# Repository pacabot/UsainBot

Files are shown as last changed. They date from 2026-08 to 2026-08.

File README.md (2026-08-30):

# UsainBot

Robot suiveur de ligne de l'équipe **Pacabot**, conçu pour l'épreuve **Formule 1** du
Tournoi National de Robotique Sumo (règlement v2.11, 2025).

Course de vitesse contre la montre sur circuit fermé : ligne noire de 19 mm sur bâche
blanche, rayon de virage minimum de 200 mm, lignes droites jusqu'à 6 m. Trois phases de
qualification, de difficulté croissante — Q3 piste nue, Q2 avec un cube de 100 mm à
éviter sans contact, Q1 avec en plus un virage à gauche escamoté et un mur de 100 mm de
haut placé à 150 mm à gauche de l'axe de la piste absente.

## Organisation

```
electronics/      projet KiCad — schéma, PCB, table de bibliothèques
  kicad-lib/      empreintes et modèles 3D propres au projet
firmware/         configuration STM32CubeMX, puis le code
mechanics/        sources FreeCAD du châssis, des supports et de la carte
documentation/    document d'architecture
rules/            règlement de l'épreuve
```

Les bibliothèques sont référencées en `${KIPRJMOD}/kicad-lib/…` : le dépôt se clone et
s'ouvre tel quel, sans chemin absolu ni variable d'environnement à déclarer.

## Architecture

Le document de conception complet — choix du microcontrôleur, schémas blocs, implantation,
élévations, affectation des broches, nomenclature JLCPCB et revue de conception en
trente-sept points — est ici :

**[`documentation/architecture-usainbot.html`](documentation/architecture-usainbot.html)**

| Fonction | Choix | JLCPCB |
|---|---|---|
| Microcontrôleur | STM32H723VGT6, Cortex-M7 550 MHz, LQFP100 | `C730142` |
| Capteur de ligne | 12 × ITR8307, pas 10 mm, émetteurs pulsés | `C81632` |
| Télémétrie | 3 × OPV302 + BPW77, détection synchrone | pose manuelle |
| Inertie | LSM6DSO, 6 axes, SPI | `C2655100` |
| Puissance moteurs | 2 × DRV8874, 6 A crête, retour de courant | `C1855818` |
| Charge | BQ25887, 2S élévateur depuis USB-C, équilibrage | `C2761614` |
| Alimentation | Pack 2S LiFePO4, bus 5,0–7,3 V, buck 3,3 V | `C3200405` |

## Géométrie

La garde au sol vaut `rayon de roue − hauteur de l'axe moteur au-dessus du dessous de
carte`. Avec les roues Pololu 40 × 7 retenues et le support N20 nu, l'axe est à 11 mm et
la garde serait de 9 mm — au-delà de la plage utile de l'ITR8307, qui travaille entre 2 et
4 mm. **Quatre millimètres d'entretoises sur mesure** sous le support portent l'axe à
15 mm et ramènent la garde à 5 mm.

Conséquence à répercuter : le décalage en Z des modèles 3D du moteur et du support, dans
`electronics/kicad-lib/Pacabot.pretty/`, devra suivre l'épaisseur d'entretoise retenue.

## Points ouverts

- **Départ par télémètre.** Le chapitre 2 du règlement énumère trois moyens de départ —
  interrupteur, bouton poussoir, jack — et cette liste se lit comme limitative. Question à
  poser aux organisateurs ; un bouton physique conforme est conservé en secours.
- **Porteuse de la télémétrie.** À choisir hors de la bande de scintillement des
  éclairages et à l'écart des 38 kHz des barrières de chronométrage, avec un codage propre
  au robot pour la réjection par corrélation. À caler sur plaque d'essai. Rester à 12 mA :
  monter en fréquence pour débloquer les 48 mA de l'OPV302 ne change pas la puissance
  moyenne, donc pas la portée — les deux régimes donnent 1,26 mW. Le seul levier de portée
  est la surface du récepteur.
- **Inclinaison des diodes.** 4° vers le haut, soudées à plat sur la carte. Le rayon bas du
  faisceau monte alors de 35 mm par mètre et n'atteint jamais la bâche, mais le centre passe
  au-dessus d'un cube de 100 mm au-delà d'environ un mètre.
- **Approvisionnement.** OPV302 et BPW77 ne sont probablement pas dans la bibliothèque
  JLCPCB : pose manuelle des six composants de la languette à prévoir.
- **Poussée de la turbine.** À mesurer sous 6,4 V et non sous les 8,4 V pour lesquels les
  ensembles ESC et brushless du commerce sont calibrés.

## Contenu tiers

- `rules/Reglement-Formule-1-v2.11.pdf` — règlement rédigé par Frédéric Giamarchi et
  Jean-Roch Vaillé pour le Tournoi National de Robotique Sumo. Publié sur
  [robot-sumo.fr](https://robot-sumo.fr), reproduit ici pour le confort de travail de
  l'équipe. Tous droits réservés à leurs auteurs.
- `mechanics/battery-holder-4xaa-1.snapshot.1/` — modèle de porte-piles téléchargé,
  conservé pour référence. Sans objet depuis le passage à un pack 2S LiFePO4.
- `electronics/kicad-lib/3d/GM12-N20_*.step` — dérivés du modèle Waveshare du
  motoréducteur. Voir `electronics/kicad-lib/README.md` pour la provenance et les réserves
  de cotation.

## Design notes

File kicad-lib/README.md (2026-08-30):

# Bibliothèque KiCad — Pacabot Junior

## Motor_GM12-N20_Bracket

Empreinte **mécanique** (aucune connexion électrique) du moteur GM12-N20 6 V 1:30
monté sur son support N20/N30.

- Origine = **milieu des deux trous de fixation**
- Axe moteur suivant **Y**, arbre de sortie vers **−Y**
- Face avant du support **6,00 mm en retrait** de la face de sortie d'axe
- 2 trous non métallisés **Ø 2,2 mm** (M2 avec jeu), **entraxe 18,00 mm**
- Emprise totale : X ±12,75 mm, Y −22,45 → +17,85 mm (40,30 mm de long)
- `F.Fab` : contour support + corps moteur + arbre — `F.SilkS` : support seul

Régénérer après une mesure : éditer les constantes en tête de
`gen_motor_footprint.py` puis `python3 gen_motor_footprint.py`.

## Modèles 3D (`3d/`)

Six fichiers STEP **colorés**, déjà positionnés sur l'origine de l'empreinte
(offset et rotation à 0 dans le `.kicad_mod`, rien à régler dans KiCad).

| Fichier | Couleur | Origine |
|---|---|---|
| `GM12-N20_bracket.step` | blanc ABS | `n20_motor_mounting_bracket001` de `../motorHolder.fcstd` |
| `GM12-N20_motor_gearbox.step` | laiton | STEP Waveshare, faces à Y ≥ 16,07 (réducteur + arbre) |
| `GM12-N20_motor_can.step` | nickel | STEP Waveshare, faces à 1,0 ≤ Y < 16,07 |
| `GM12-N20_motor_encoder.step` | sombre | STEP Waveshare, faces à Y < 1,0 |
| `Pololu_wheel_40x7_hub.step` | blanc | STEP officiel Pololu, faces à r ≤ 18,3 mm |
| `Pololu_wheel_40x7_tire.step` | noir | STEP officiel Pololu, faces à r > 18,3 mm |

La roue est le modèle officiel Pololu du 40×7 mm **blanc** — exactement la
référence 1454 achetée. Séparation moyeu/gomme au rayon 18,25 mm, d'après le
plan coté Pololu : moyeu Ø36,5 mm, hors-tout Ø40,0 mm.

Position de la roue : emmanchée à fond, face extérieure au bout d'arbre.

### Couleurs

KiCad 10 n'utilise plus que du STEP (aucun `.wrl` livré) : la couleur doit être
portée par le fichier lui-même. FreeCAD en mode console ne sait pas les écrire —
pas de `ViewObject`. Les entités `COLOUR_RGB` / `STYLED_ITEM` sont donc ajoutées
en post-traitement par `colorize_step.py`, sur le même motif que les modèles
livrés avec KiCad. Pour changer une teinte : éditer `PALETTE` en tête du script,
régénérer le STEP concerné, puis relancer `python3 colorize_step.py`.

## Provenance des cotes

| Cote | Valeur | Source |
|---|---|---|
| **Entraxe des trous** | **18,00 mm** | vue de dessus de la datasheet Handson `GA12-N20-Bracket.pdf` — **confirmé au pied à coulisse sur la pièce réelle** |
| Diamètre des trous | M2 (écrou hexagonal) | datasheet — porté à 2,20 mm sur la carte pour le jeu |
| Largeur hors-tout | 25,00 mm | datasheet |
| Profondeur | 11,50 mm | datasheet (dont 8,50 mm pour la zone des oreilles) |
| **Retrait support / face de sortie d'axe** | **6,00 mm** | **mesuré sur le montage réel** |
| Section moteur | 10 × 12 mm | plan coté Waveshare + STEP |
| Longueur totale moteur | 40,30 mm | STEP Waveshare |
| Arbre | Ø3 mm, méplat D 2,5 mm, 9,2 mm | STEP Waveshare |

## Réserves

1. **Le 3D du support ne correspond pas exactement à la pièce réelle.**
   `n20_motor_mounting_bracket001` (extrait de `../motorHolder.fcstd`) mesure
   27,50 mm de large pour un entraxe de 18,50 mm, alors que la pièce achetée
   fait 25,00 mm pour 18,00 mm d'entraxe. C'est un modèle téléchargé, pas un
   relevé de la pièce. **L'empreinte est juste** (cotes datasheet vérifiées au
   pied à coulisse) ; seul le rendu 3D est indicatif, avec 0,25 mm d'écart par
   trou et 1,25 mm par côté.

2. **Attention au texte de la datasheet Handson** : son résumé annonce
   « *Pitch: about 16 mm* », ce qui est faux. La cote de 18,0 mm portée sur la
   vue de dessus, dont les lignes d'attache aboutissent au centre des logements
   d'écrou, est la bonne.

3. **Le 3D du moteur est un Waveshare DCGM-N20-12V-EN-200RPM (12 V, 1:150)**,
   pas le GM12-N20 6 V 1:30 réellement acheté. Même famille et mêmes cotes
   d'enveloppe, mais le bloc encodeur en bout diffère : le modèle porte un
   connecteur ZH1.5-6PIN là où la pièce réelle a un faisceau.

4. Le bloc encodeur du modèle descend à Z = −0,41 mm (très légèrement sous le
   plan de la carte) et culmine à Z = 18,50 mm.

5. Le sens de montage du support est **confirmé** : la face à 7,25 mm de l'axe
   des trous est bien côté arbre. Le support serre le **corps du moteur**, pas le
   réducteur — il couvre 3,03 mm de réducteur et 8,47 mm de moteur.

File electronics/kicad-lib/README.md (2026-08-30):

# Bibliothèque KiCad — UsainBot

## Motor_GM12-N20_Bracket

Empreinte **mécanique** (aucune connexion électrique) du moteur GM12-N20 6 V 1:30
monté sur son support N20/N30.

- Origine = **milieu des deux trous de fixation**
- Axe moteur suivant **Y**, arbre de sortie vers **−Y**
- Face avant du support **6,00 mm en retrait** de la face de sortie d'axe
- 2 trous non métallisés **Ø 2,2 mm** (M2 avec jeu), **entraxe 18,00 mm**
- Emprise totale : X ±12,75 mm, Y −22,45 → +17,85 mm (40,30 mm de long)
- `F.Fab` : contour support + corps moteur + arbre — `F.SilkS` : support seul

Régénérer après une mesure : éditer les constantes en tête de
`gen_motor_footprint.py` puis `python3 gen_motor_footprint.py`.

## Symboles (`Pacabot.kicad_sym`)

Neuf symboles absents des bibliothèques KiCad, ou dont le typage de broches
rendait l'ERC inexploitable. Régénérer avec `../tools/gen_lib.py`.

| Symbole | Pourquoi il est là |
|---|---|
| `DRV8874PWPR` | KiCad ne fournit que les DRV8870/71/72. Brochage HTSSOP-16 saisi depuis la fiche TI SLVSF66A : `EN/IN1` 1, `PH/IN2` 2, `nSLEEP` 3, `nFAULT` 4, `VREF` 5, `IPROPI` 6, `IMODE` 7, `OUT1` 8, `PGND` 9, `OUT2` 10, `VM` 11, `VCP` 12, `CPH` 13, `CPL` 14, `GND` 15, `PMODE` 16, pad thermique 17 |
| `AO4407A` | Canal P SO-8 pour la protection anti-inversion. Les `Q_PMOS_*` de KiCad n'ont que trois broches : impossible de les faire correspondre aux 1-3 source / 4 grille / 5-8 drain du boîtier |
| `LSM6DSOTR` | Copie de `Sensor_Motion:LSM6DS3` — même LGA-14, même brochage. `SDX` et `SCX` retypées en passif : elles sont strappées à la masse, et les laisser bidirectionnelles fait crier l'ERC sans raison |
| `ITR8307` | Copie de `Sensor_Proximity:ITR8307-S17-TR8`, phototransistor retypé en passif. « Collecteur ouvert » relié à un rail est un défaut d'ERC alors que c'est exactement le montage voulu |
| `SW_Nav_5Way` | Switch 5 directions à commun unique. **Empreinte à confirmer** sur la référence retenue (LCSC C3674) : le champ est laissé vide exprès |
| `VBAT` `VPACK` `+3V3A` `+3V3_BLE` | Symboles d'alimentation des quatre rails propres au projet |

### Réserve

Le `VL53L1CBV0FY/1` utilise le symbole standard `Sensor_Distance:VL53L1CXV0FY1`
et l'empreinte `Sensor_Distance:ST_VL53L1x`. Même boîtier optique et même
brochage ; seule la valeur a été changée. À revérifier si le composant
réellement approvisionné n'est pas un CB.

## Modèles 3D (`3d/`)

Six fichiers STEP **colorés**, déjà positionnés sur l'origine de l'empreinte
(offset et rotation à 0 dans le `.kicad_mod`, rien à régler dans KiCad).

| Fichier | Couleur | Origine |
|---|---|---|
| `GM12-N20_bracket.step` | blanc ABS | `n20_motor_mounting_bracket001` de `../motorHolder.fcstd` |
| `GM12-N20_motor_gearbox.step` | laiton | STEP Waveshare, faces à Y ≥ 16,07 (réducteur + arbre) |
| `GM12-N20_motor_can.step` | nickel | STEP Waveshare, faces à 1,0 ≤ Y < 16,07 |
| `GM12-N20_motor_encoder.step` | sombre | STEP Waveshare, faces à Y < 1,0 |
| `Pololu_wheel_40x7_hub.step` | blanc | STEP officiel Pololu, faces à r ≤ 18,3 mm |
| `Pololu_wheel_40x7_tire.step` | noir | STEP officiel Pololu, faces à r > 18,3 mm |

La roue est le modèle officiel Pololu du 40×7 mm **blanc** — exactement la
référence 1454 achetée. Séparation moyeu/gomme au rayon 18,25 mm, d'après le
plan coté Pololu : moyeu Ø36,5 mm, hors-tout Ø40,0 mm.

Position de la roue : emmanchée à fond, face extérieure au bout d'arbre.

### Couleurs

KiCad 10 n'utilise plus que du STEP (aucun `.wrl` livré) : la couleur doit être
portée par le fichier lui-même. FreeCAD en mode console ne sait pas les écrire —
pas de `ViewObject`. Les entités `COLOUR_RGB` / `STYLED_ITEM` sont donc ajoutées
en post-traitement par `colorize_step.py`, sur le même motif que les modèles
livrés avec KiCad. Pour changer une teinte : éditer `PALETTE` en tête du script,
régénérer le STEP concerné, puis relancer `python3 colorize_step.py`.

## Provenance des cotes

| Cote | Valeur | Source |
|---|---|---|
| **Entraxe des trous** | **18,00 mm** | vue de dessus de la datasheet Handson `GA12-N20-Bracket.pdf` — **confirmé au pied à coulisse sur la pièce réelle** |
| Diamètre des trous | M2 (écrou hexagonal) | datasheet — porté à 2,20 mm sur la carte pour le jeu |
| Largeur hors-tout | 25,00 mm | datasheet |
| Profondeur | 11,50 mm | datasheet (dont 8,50 mm pour la zone des oreilles) |
| **Retrait support / face de sortie d'axe** | **6,00 mm** | **mesuré sur le montage réel** |
| Section moteur | 10 × 12 mm | plan coté Waveshare + STEP |
| Longueur totale moteur | 40,30 mm | STEP Waveshare |
| Arbre | Ø3 mm, méplat D 2,5 mm, 9,2 mm | STEP Waveshare |

## Réserves

1. **Le 3D du support ne correspond pas exactement à la pièce réelle.**
   `n20_motor_mounting_bracket001` (extrait de `../motorHolder.fcstd`) mesure
   27,50 mm de large pour un entraxe de 18,50 mm, alors que la pièce achetée
   fait 25,00 mm pour 18,00 mm d'entraxe. C'est un modèle téléchargé, pas un
   relevé de la pièce. **L'empreinte est juste** (cotes datasheet vérifiées au
   pied à coulisse) ; seul le rendu 3D est indicatif, avec 0,25 mm d'écart par
   trou et 1,25 mm par côté.

2. **Attention au texte de la datasheet Handson** : son résumé annonce
   « *Pitch: about 16 mm* », ce qui est faux. La cote de 18,0 mm portée sur la
   vue de dessus, dont les lignes d'attache aboutissent au centre des logements
   d'écrou, est la bonne.

3. **Le 3D du moteur est un Waveshare DCGM-N20-12V-EN-200RPM (12 V, 1:150)**,
   pas le GM12-N20 6 V 1:30 réellement acheté. Même famille et mêmes cotes
   d'enveloppe, mais le bloc encodeur en bout diffère : le modèle porte un
   connecteur ZH1.5-6PIN là où la pièce réelle a un faisceau.

4. Le bloc encodeur du modèle descend à Z = −0,41 mm (très légèrement sous le
   plan de la carte) et culmine à Z = 18,50 mm.

5. Le sens de montage du support est **confirmé** : la face à 7,25 mm de l'axe
   des trous est bien côté arbre. Le support serre le **corps du moteur**, pas le
   réducteur — il couvre 3,03 mm de réducteur et 8,47 mm de moteur.

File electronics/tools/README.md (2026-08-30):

# Générateur du schéma

Les huit `*.kicad_sch` de `electronics/` et la bibliothèque
`kicad-lib/Pacabot.kicad_sym` sont **produits par ces scripts**, à partir du
brochage et des choix de composants du document d'architecture.

```sh
python3 gen_lib.py      # kicad-lib/Pacabot.kicad_sym  (puis normalisé par kicad-cli)
python3 design.py       # UsainBot.kicad_sch + 01-power … 07-comms
```

Dans cet ordre : `design.py` recopie chaque symbole dans le schéma et KiCad
compare cette copie à la librairie. Si la librairie n'a pas été normalisée
avant, chaque symbole lève un avertissement « ne correspond pas à la copie ».

> **Le schéma est écrasé à chaque exécution.** À partir du moment où tu retouches
> quoi que ce soit dans Eeschema, ces scripts deviennent une archive de la
> version initiale — ne les relance pas sans avoir reporté tes modifications.

## Découpage

| Fichier | Rôle |
|---|---|
| `sexp.py` | lecture / écriture des S-expressions KiCad |
| `kigen.py` | placement, raccordements, vérifications géométriques |
| `gen_lib.py` | les neuf symboles propres au projet |
| `design.py` | les sept feuilles et la feuille racine |

Les bibliothèques KiCad sont cherchées dans `/Applications/KiCad/…`, puis
`/usr/share/kicad`. Sur une autre installation : `KICAD_SHARE=/chemin python3 …`.

## Conventions

**Tout passe par des étiquettes.** Chaque broche reçoit un tronçon de 2,54 mm
(5,08 mm sur le microcontrôleur) terminé par une étiquette locale, une étiquette
globale ou un symbole d'alimentation. Aucun fil long, donc aucun croisement à
arbitrer, et une netlist qui se relit signal par signal. Les feuilles
communiquent par étiquettes globales plutôt que par entrées de feuille : un bloc
se lit seul, et renommer un signal ne demande pas de retoucher la racine.

**Les étiquettes restent horizontales**, y compris au bout d'un tronçon
vertical. Écrite le long du fil, une étiquette traverse le composant placé
au-dessus ou au-dessous : c'est exactement ce qui arrivait aux deux `VBAT_SENSE`
du pont diviseur R119/R120, chacune écrite dans le corps de l'autre résistance.

**Une seule étiquette par net, même sur plusieurs broches.** Les broches
confondues du BQ25887 (`PMID`, `SW`, `SNS`, `BAT` sont doublées) et les grappes
étalées — quatre drains de l'AO4407A, cinq masses de l'embase USB-C — sont
ramenées par `cx_bar()` sur une barre commune terminée par une étiquette unique,
au lieu d'en empiler autant que de broches.

**Pas de coude.** Un tronçon part toujours tout droit dans l'axe de sa broche.
Deux tronçons parallèles ne se croisent jamais ; un coude, lui, retombe sur la
broche voisine et court-circuite deux nets sans que rien ne le signale à
l'écran. Les symboles d'alimentation ont leur broche à l'origine : les tourner
ne déplace rien, ce qui permet de les orienter proprement sans coude.

**Grille de 1,27 mm.** Toutes les coordonnées y sont ramenées à l'écriture.
Sinon KiCad refuse la connexion et l'ERC se remplit de `endpoint_off_grid`.

## Vérifications

`design.py` refuse de terminer en silence sur trois classes d'erreur :

- une empreinte qui n'existe pas dans les bibliothèques installées ;
- deux tronçons colinéaires de nets différents qui se recouvrent, ou une
  extrémité qui tombe au milieu d'un fil étranger — le court-circuit
  géométrique, invisible à l'œil sur une feuille A3 ;
- un composant ou une note qui tombe dans le cartouche ;
- deux boîtes englobantes qui se recouvrent — corps, référence, valeur,
  étiquette, symbole d'alimentation, note. Un texte écrit par-dessus un boîtier
  ne casse rien électriquement et ne sera donc jamais signalé par l'ERC, mais
  rend la feuille illisible.

Ces contrôles ne remplacent pas l'ERC, ils attrapent ce qui, sans eux,
n'apparaîtrait qu'après coup dans la netlist. L'état de référence est
**0 erreur, 0 avertissement** :

```sh
cd .. && kicad-cli sch erc --severity-all UsainBot.kicad_sch
```

Le contrôle `single_global_label` est activé dans `UsainBot.kicad_pro` : une
étiquette globale qui n'apparaît qu'une fois est une faute de frappe, pas un
signal.

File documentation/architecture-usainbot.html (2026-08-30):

Pacabot · UsainBot · architecture matérielle

# Architecture UsainBot

Robot suiveur de ligne pour le Tournoi National de Robotique — épreuve Formule 1, règlement v2.11. Cœur STM32H7, chaîne de mesure 12 voies, deux ponts en H à mesure de courant, sortie ESC pour turbine d'appui, alimentation 2S LiFePO4 rechargeable en USB-C. Tous les composants actifs sont sourçables chez JLCPCB.

Cible STM32H723VGT6 · LQFP100 Règlement TNRS F1 v2.11 (2025) Assemblage JLCPCB PCBA 4 couches Révision 30 août 2026

§1

## Ce que le règlement impose au matériel

Le règlement n'est pas qu'un cadre sportif : sept de ses articles se traduisent directement en composants sur la carte. Cette lecture conditionne tout le reste du document.

Article | Texte | Conséquence matérielle
Ch. 2 | Interrupteur de mise en marche et d'arrêt facile d'accès | Interrupteur mécanique 5 A dans la ligne batterie, accessible robot posé — pas seulement le connecteur d'accu
Ch. 2 | Départ par interrupteur, bouton poussoir ou jack | Énumération limitative : le geste devant le télémètre n'y figure pas. Bouton START physique conservé comme moyen conforme, geste devant le télémètre en complément — voir §8, point 02
Ch. 2 | Moyens de communication inhibés au moment du départ | Coupure d'alimentation matérielle du module BLE + LED témoin visible du jury
Ch. 3 | Marques départ/arrivée à droite, 19 × 50 mm, à 40 mm du centre de piste | La barrette doit couvrir au moins ±55 mm, sinon le robot ne voit pas l'arrivée
Ch. 3 | Croisements perpendiculaires de deux segments | Barrette symétrique pour distinguer « toute la largeur noire » (croisement) de « côté droit seul » (marque)
Ch. 5 art. 1 | Calibration et configuration sans outillage, seul un petit tournevis accepté | IHM embarquée obligatoire : boutons + OLED + buzzer, réglages en flash
Ch. 5 art. 1 | Changement de batterie en échange standard pendant les 3 minutes | Connecteur d'accu accessible et détrompé, pack interchangeable, calibration non perdue au débranchement
Ch. 5 art. 2 | Franchir l'arrivée, s'arrêter seul en moins de 1 m, rester immobile 5 s | Freinage actif à pleine puissance + détection d'immobilité par IMU
Ch. 7 (Q2) | Cube de 100 mm visible par capteurs de distance infrarouge, contact interdit | Télémétrie avant et diagonale, détection à > 60 cm pour avoir le temps d'esquiver
Ch. 8 (Q1) | Piste absente dans un virage à gauche, mur de 10 cm de haut à 15 cm à gauche du centre virtuel | Télémètre latéral gauche visé à l'horizontale à 45 mm du sol, plus odométrie fiable pour tenir le virage sans ligne
Ch. 10 | Éclairage non uniforme et variable, flashs interdits | Émetteurs IR pulsés et soustraction de l'ambiante à chaque cycle — un capteur en continu est disqualifiant en pratique
Ch. 5 art. 1 | Le robot peut apprendre le tracé par lui-même | Mémoire non volatile pour la carte du circuit et le profil de vitesse — le plus gros levier de chrono

Chiffre à garder en tête

Rayon de virage minimum 20 cm. À 2,5 m/s, l'accélération centripète vaut v²/r = 31 m/s², soit 3,2 g. Aucun pneu de robot ne tient ça sans appui aérodynamique. C'est la mécanique, pas l'électronique, qui plafonnera ton chrono — la carte doit donc au minimum prévoir de quoi alimenter et piloter une turbine.

§2

## Choix du microcontrôleur

Entre F7 et H7, l'arbitrage se joue sur la chaîne d'acquisition analogique, pas sur la puissance de calcul : la boucle de suivi de ligne demande une poignée de MIPS, mais un échantillonnage synchronisé sur les impulsions IR, à cadence élevée et sans jitter.

Le STM32H723VGT6 l'emporte : Cortex-M7 à 550 MHz, 1 Mo de flash, 564 Ko de RAM, trois ADC dont deux en 16 bits capables de conversion simultanée, et surtout un boîtier LQFP100 qui reste routable sur 4 couches sans BGA. Il est référencé C730142 chez JLCPCB.

550MHz Cortex-M7

2 × 16 bitsADC simultanés

1 MoFlash interne

564 KoRAM

82E/S en LQFP100

### Pourquoi pas un F7

Le STM32F767 conviendrait fonctionnellement, mais ses ADC sont en 12 bits et plafonnent à 2,4 Méch/s ; la dynamique gagnée par le 16 bits du H7 se paie directement en qualité de position de ligne quand le contraste s'effondre sous éclairage variable (chapitre 10 du règlement). À prix et disponibilité JLCPCB comparables, il n'y a pas de raison de prendre le F7.

Piège H7 classique

Le H7 embarque un régulateur à découpage interne (SMPS) en plus du LDO. Le câblage de VDDSMPS / VLXSMPS / VFBSMPS et le choix du mode d'alimentation doivent être figés au schéma : un H7 mal strappé ne démarre pas, ou démarre puis se bloque au premier passage en VOS0. Suis à la lettre la note d'application AN5312 pour le mode « LDO seul », le plus simple ici.

§3

## Architecture et implantation

Fig. 1 — Répartition des bus. Les douze voies de la barrette occupent ADC1 et ADC2 en conversion simultanée ; la surveillance de bord est isolée sur ADC3 pour ne jamais perturber la cadence de la barrette.

### Implantation, vue de dessus

Proposition de placement dans une carte de 120 × 180 mm, largement sous la limite de 200 × 200 mm. Trois principes gouvernent ce plan : les capteurs de ligne le plus en avant possible, le microcontrôleur juste derrière eux pour raccourcir les pistes analogiques, et toute la masse — pack et moteurs — concentrée sur l'essieu arrière.

Fig. 2 — Implantation proposée, cotes indicatives à recaler sur ton châssis. Les six diodes de télémétrie sont soudées sur la carte elle-même, boîtier couché. Le pack et les moteurs concentrent la masse sur l'essieu ; la turbine, juste en avant, souffle à travers une découpe de la carte.

### Hauteurs et angles de montage

Deux familles de capteurs sur la même carte, deux contraintes verticales à satisfaire — et elles se satisfont sans carte fille, parce qu'elles ne jouent pas dans le même plan. Les capteurs de ligne regardent vers le bas depuis le dessous ; les diodes de télémétrie sont soudées sur le dessus, boîtier couché, et visent vers l'avant en étant inclinées vers le haut.

Une relation gouverne la première : garde au sol = rayon de roue − hauteur de l'axe moteur au-dessus du dessous de carte. Les roues retenues sont des Pololu 40 × 7, soit un rayon de 20 mm. Le support N20 nu place l'arbre à 11 mm au-dessus du dessous de carte, ce qui donnerait 9 mm de garde — bien trop pour l'ITR8307. La correction est mécanique et se chiffre exactement : 4 mm d'entretoises sur mesure sous le support portent l'axe à 15 mm, et la garde retombe à 5 mm. C'est le bon endroit pour régler, parce qu'une entretoise se retaille en dix minutes là où un PCB se recommande.

La seconde tient à l'ouverture réelle du faisceau, et c'est là que la fiche technique tranche.

Fig. 3 — Inclinaison de 4°, demi-angle de 2° : le rayon bas monte de 35 mm par mètre et n'atteint jamais la bâche, tandis que le centre du faisceau reste sur un cube de 100 mm jusqu'à environ un mètre. Incliner davantage sécuriserait le sol mais raccourcirait la portée utile — à 6°, le faisceau passe au-dessus du cube dès 850 mm.

### Ce que dit la fiche technique de l'OPV302

Le composant est un VCSEL de 850 nm en boîtier TO-46 à lentille dôme, et non une diode laser à émission par la tranche. Cela change deux choses par rapport à ce que j'avais supposé.

Paramètre | Valeur | Ce que ça implique ici
Divergence du faisceau | 4° FWHM | Demi-angle de 2°. Étroit, mais pas collimaté : la tache fait 42 mm à 600 mm et 70 mm à 1 m — largement dans un cube de 100 mm
Puissance optique | 1,5 mW à 7 mA | Concentrée dans 4°, c'est ce qui rend le mètre atteignable
Rendement de pente | 0,28 mW/mA | À 12 mA : environ 2,5 mW crête
Courant direct continu max | 12 mA | C'est le vrai plafond en régime porteuse
Courant pulsé max | 48 mA — 1 µs, 10 % | Piège : à 20 kHz en carré, la période haute dure 25 µs. Le mode 48 mA est donc inaccessible
Courant de seuil | 3 mA | Sous ce seuil, plus d'effet laser : la modulation doit rester au-dessus
Sensibilité ESD | notée au datasheet | Précautions au montage, et protection sur la ligne de commande

La conséquence pratique est nette : avec un récepteur à phototransistor, dont la bande passante impose de rester vers 10–20 kHz, tu es limité à 12 mA et environ 2,5 mW crête. C'est déjà 1,7 fois la puissance nominale, et cela suffit — c'est le régime dans lequel ton mètre a été mesuré. Le mode 48 mA n'a de sens qu'avec des impulsions de 1 µs, donc une porteuse au-delà de 100 kHz, donc une photodiode et un amplificateur transimpédance à la place du phototransistor. C'est un autre projet ; ne l'ouvre que si la portée manque.

### Faut-il monter en fréquence pour débloquer les 48 mA ?

La question est naturelle : si le mode 48 mA n'est refusé qu'à cause de la durée d'impulsion, il suffit de raccourcir les impulsions et de monter la cadence. Techniquement oui — 1 µs à 100 kHz, c'est exactement les 10 % de rapport cyclique autorisés. Mais le calcul de ce que ça rapporte est décevant, et il tient en une ligne de tableau.

Régime | Crête | Rapport cyclique | Puissance moyenne
Porteuse 20 kHz, carré | 2,52 mW | 50 % | 1,26 mW
Impulsions 1 µs à 100 kHz | 12,60 mW | 10 % | 1,26 mW

Rigoureusement la même puissance moyenne. Ce n'est pas une coïncidence : les deux valeurs de la fiche technique sont construites autour de la même limite thermique de la puce. Or un détecteur synchrone intègre sur de nombreuses périodes, et ce qu'il accumule est une énergie — le produit de la puissance moyenne par le temps de mesure. Le bruit d'ambiance, lui, a une densité spectrale plate : élargir la bande pour laisser passer des impulsions de 1 µs le laisse entrer en proportion. Le rapport signal sur bruit atteint en un temps de mesure donné est donc identique dans les deux régimes.

Ce que la montée en fréquence coûte, en revanche, est bien réel. Une impulsion de 1 µs demande plusieurs centaines de kilohertz de bande passante côté réception : le phototransistor est hors jeu, il faut une photodiode et un amplificateur transimpédance par voie, soit trois op-amps et une disposition soignée. Pour un gain nul en portée.

Le vrai levier est du côté du récepteur

Le signal collecté est proportionnel à la surface active du détecteur, et cette voie-là n'a aucune contrepartie de sécurité puisqu'elle n'ajoute pas un milliwatt d'émission. Passer d'un phototransistor de l'ordre du millimètre carré à une photodiode BPW34 de 7,5 mm² multiplie le signal par 7,5 — soit, en 1/d², une portée multipliée par 2,7. Aucun réglage côté émetteur n'approche ce facteur. Une simple lentille de collecte devant le détecteur joue dans la même catégorie. Si un jour la portée manque, commence par là.

Conclusion pratique : reste à 12 mA sur une porteuse de 10 à 20 kHz avec le phototransistor. Ne monte en fréquence que si tu as une raison qui n'est pas la portée — une bande encombrée par les émetteurs des concurrents, ou un besoin de latence inférieure à la centaine de microsecondes.

§4

## Sous-systèmes

### Capteur de ligne

C'est la pièce qui décide du chrono, et c'est aussi la seule que tu dois concevoir toi-même. Douze capteurs réflectifs ITR8307 au pas de 10 mm couvrent 110 mm, soit ±55 mm autour de l'axe : assez pour voir les marques de départ et d'arrivée placées à 40 mm à droite, et pour reconnaître un croisement au fait que toute la barrette passe au noir simultanément.

Les émetteurs sont câblés en deux bancs (pairs et impairs), chacun commuté par un MOSFET AO3400A. La séquence d'acquisition, déclenchée par TIM6 à 2 kHz, enchaîne : mesure tous émetteurs éteints (ambiante), mesure banc A, mesure banc B. La soustraction élimine l'éclairage de salle — exigence directe du chapitre 10 — et l'alternance des bancs supprime la diaphonie entre voisins. Attention : cette soustraction est numérique, et elle ne suffit qu'ici, à 3 mm de la bâche, où le signal est abondant. Le télémètre analogique, lui, joue dans un tout autre régime et demande une suppression du continu en amont du gain — comparaison des deux plus bas.

Les douze capteurs sont implantés sous le bord avant de la carte mère, et non sur une carte fille. Alimente-les depuis 3V3A, la même référence que VREF+ : la mesure devient ratiométrique et l'ondulation résiduelle du buck s'annule.

### Une seule carte, sans exception

La carte fille sur nappe FFC n'avait que deux arguments : le bruit, et le réglage de hauteur. Le premier ne tient pas — un plan de masse continu sur 4 couches est meilleur qu'une nappe, quelle que soit la façon dont on alterne signal et masse dedans. Le second tombe avec les entretoises, qui règlent l'assiette du robot entier.

Restait la question des télémètres, que je croyais condamnés à une carte verticale. Elle disparaît elle aussi dès lors que les diodes sont soudées à plat sur la carte et inclinées : le faisceau n'a pas besoin de partir de haut, il a besoin de ne pas descendre. Boîtier couché, pattes cintrées, quatre degrés vers le haut, et l'axe optique à une douzaine de millimètres du sol suffit — c'est la pratique du micromouse, et elle vaut ici pour la même raison.

Capteur | Position | Contrainte
ITR8307, barrette de ligne | dessous, 3 mm du sol | Au-delà de 4 mm, le contraste noir/blanc s'effondre
OPV302 et BPW77, télémétrie | dessus, axe à 12 mm, + 4° | Le rayon bas du faisceau doit monter, pas la source

Une carte, un fichier de fabrication, une commande, aucun connecteur intermédiaire et aucune poutre en porte-à-faux à l'avant du robot. C'est la configuration la plus robuste des trois qu'on aura envisagées.

Ce qui remplace le réglage perdu

Des diodes soudées ne se règlent plus en hauteur, et leur inclinaison se joue à quelques degrés près. Deux garde-fous. Le premier est mécanique : monte-les sur pattes cintrées plutôt qu'en montage traversant rigide, pour pouvoir corriger l'angle au montage — c'est précisément ce que permet le boîtier TO-46. Le second est logiciel : un courant d'émetteur piloté rattrape une portée insuffisante sans toucher au matériel.

Deux garde-fous pour ne pas dépendre d'une mesure de hauteur faite avant le routage. D'abord, rends le courant des émetteurs pilotable : en modulant le rapport cyclique sur le MOSFET de banc, tu rattrapes en logiciel une hauteur de 6 mm au lieu de 3. Ensuite, déplace le réglage vers le châssis — trous oblongs sur les supports moteurs plutôt que sur les capteurs. C'est le bon endroit : tu règles l'assiette du robot entier, pas un sous-ensemble.

#### Télémétrie

3 × OPV302 + BPW77 · détection synchrone

Avant pour voir venir le cube, avant-gauche à 45° pour anticiper la disparition de la piste, latéral gauche à 90° pour asservir sur le mur de la Q1. Trois stations émetteur–récepteur identiques, soudées sur la carte mère.

- Émetteurs multiplexés dans le temps : un seul éclaire à la fois, ce qui supprime la diaphonie entre visées et donne au passage une mesure du couplage parasite
- Intégration adaptée à la cible : 1 ms pour le mur, proche et lumineux, donc 1 kHz d'asservissement ; 10 ms pour le cube, lointain, donc 100 Hz
- Diodes soudées sur la carte, boîtier couché et incliné de 4° : le faisceau ne touche jamais la bâche sans qu'il faille les surélever
- ADC3 leur est dédié en conversion continue, échantillonnage à quatre fois la porteuse
- Aucun trafic I²C dans la boucle critique

#### Inertie et dérapage

LSM6DSOTR — C2655100 · SPI2

Le dérapage ne se voit pas aux encodeurs : quand les deux roues glissent ensemble, l'odométrie reste cohérente et fausse. Il faut une référence externe.

- Lacet gyro comparé au lacet odométrique (vd − vg)/e — l'écart est le dérapage
- Accélération latérale mesurée contre la consigne : donne la limite d'adhérence réelle du jour
- Détection d'immobilité pour valider les 5 s d'arrêt
- À placer au centre de rotation, près de l'essieu moteur

#### Motorisation

2 × DRV8874PWPR — C1855818

Un pont complet par moteur, 6 A crête, 200 mΩ, pompe de charge intégrée et surtout une sortie IPROPI qui recopie le courant moteur — de quoi détecter un calage, mesurer la traction et faire de la coulométrie.

- PMODE en mode IN1/IN2 : freinage actif et décroissance rapide contrôlés
- nSLEEP rappelé au 0 V, nFAULT lu par le MCU
- Pad thermique cousu de vias, 2 × 100 µF faible ESR au plus près
- 100 nF X7R aux bornes de chaque moteur, fils torsadés

#### Odométrie

TIM3 et TIM8 en mode encodeur

Encodeurs à effet Hall en quadrature sur l'arbre moteur, alimentés en 3,3 V, connecteur JST-PH 6 points par moteur (moteur + encodeur sur la même nappe).

- Compteurs 16 bits : à 840 pts/tour et roue de 27 mm, un tour de compteur vaut 2,7 m — sans risque de débordement entre deux lectures à 1 kHz
- Filtre d'entrée du timer activé, plus 100 Ω / 1 nF en série
- Le SWO occupe PB3, ce qui interdit TIM2 ; d'où le choix de deux timers 16 bits plutôt qu'un 32 bits

#### Interface homme-machine

SSD1306 I²C · switch 5 directions · buzzer

Le règlement n'autorise qu'un petit tournevis au bord de piste : toute la configuration passe donc par l'écran et le switch, et les réglages vivent en flash.

- Switch 5 directions (haut, bas, gauche, droite, appui) : navigation à deux dimensions dans les menus, une seule pièce, un seul trou dans le capot
- OLED sur I²C2, jamais rafraîchi pendant une tentative (transfert bloquant de ~30 ms)
- Buzzer passif sur TIM17 : le seul retour lisible quand le robot est au sol
- Bouton START séparé + embase « jack de départ » conservés — voir la séquence ci-dessous

#### Traces et télémétrie

W25Q128 SPI3 · port BLE · USB CDC

Trois canaux, trois usages distincts. Ne compte pas sur le BLE pour du log rapide : il plafonne à quelques kilo-octets par seconde.

- Flash SPI : log 1 kHz de 20 signaux pendant un tour complet, puis vidage
- USB CDC : vidage rapide et mise à jour DFU sans sonde
- BLE : supervision légère et réglages à distance, sur module détachable

#### Turbine d'appui

Embase ESC 3 points · TIM4 CH3 sur PB8

Le moteur brushless n'est pas piloté par la carte : c'est l'ESC qui s'en charge, et la carte ne lui envoie qu'une consigne. L'interface se réduit donc à trois fils, mais deux détails la rendent dangereuse si on les néglige.

- Broche centrale non connectée : la plupart des ESC sortent 5 ou 6 V de BEC sur ce fil. Reliée au rail 3,3 V, elle emporte toute la carte
- Signal servo 1–2 ms à 50–500 Hz, ou DShot via TIM4 et DMA — pas de calibration, et le régime réel remonte en télémétrie, ce qui permet de voir la turbine décrocher
- Puissance prise directement sur VBAT, en amont des ponts moteurs, avec son propre découplage
- L'armement de l'ESC fait partie de la séquence de pré-départ, pas du démarrage du firmware

### Combien de télémètres, et de quel type

Tu as raison de tiquer : cinq, c'était de la symétrie, pas du besoin. En revenant au règlement, il n'y a que deux obligations de détection, et une seule d'entre elles demande de la vitesse.

Besoin | Source | Visée | Contrainte dominante
Voir venir le cube de 100 mm | Ch. 7 — Q2 | avant, 0° | Portée : il faut le voir à 60 cm pour avoir le temps de planifier l'esquive
Suivre le mur quand la piste disparaît | Ch. 8 — Q1 | gauche, 90° | Cadence : c'est un asservissement, il tourne à 1 kHz
Anticiper l'entrée dans la zone sans piste | Confort | avant-gauche, 45° | Ni l'un ni l'autre — utile, pas indispensable

Les deux visées à droite que j'avais mises ne servaient qu'à rendre le robot symétrique. Or le règlement est explicitement asymétrique : le virage escamoté est à gauche, le mur est à gauche. Quant au cube, il est garanti à plus d'un mètre de tout virage, donc toujours en ligne droite : tu esquives du côté que tu veux, et tu choisis toujours le même. Deux capteurs de moins, six euros et deux adresses I²C économisés.

### Ton capteur analogique OPV302 : la détection synchrone change l'échelle

Un mètre de portée avec un OPV302 et un BPW77, c'est parfaitement crédible, et ça invalide l'objection en 1/d² prise seule. Ce qui la lève, c'est le traitement : retirer la composante continue avant le gain, puis moduler et démoduler en synchrone. Ces deux gestes ne réduisent pas la perte optique — ils rendent le signal restant exploitable, ce qui n'est pas la même chose.

La distinction est facile à manquer parce que le mot « soustraction d'ambiante » recouvre deux opérations très différentes. Sur la barrette de ligne, je décris une soustraction numérique : on mesure émetteurs éteints, puis allumés, et on retranche après conversion. À 3 mm de la bâche, le signal est énorme et cela suffit largement. À un mètre, cette méthode ne mène nulle part : le continu ambiant a déjà consommé toute la dynamique de l'étage d'entrée avant même que l'ADC ne voie quoi que ce soit. Il faut le supprimer en amont, dans l'analogique, pour pouvoir ensuite appliquer 60 à 80 dB de gain sur la seule composante modulée.

Régime | Barrette de ligne | Télémètre analogique
Distance | 3 mm | 150 à 1000 mm
Signal disponible | Abondant | Rare — c'est toute la difficulté
Contrainte | Débit : 12 voies à cadencer | Sensibilité : une voie à extraire du bruit
Rejet de l'ambiante | Soustraction numérique en 3 phases | Couplage alternatif puis détection synchrone
Cadence ADC | 2 kHz × 12 voies | 4 × la porteuse sur une voie, en continu

### Ce que la chaîne doit comporter

#### Émission codée

OPV302 · sortie timer

- Porteuse au-dessus de la bande de scintillement des éclairages : le 100 Hz du secteur et ses harmoniques, la MLI des LED, montent à quelques kHz. Une porteuse à 10–20 kHz s'en dégage nettement
- Les barrières de chronométrage sont elles aussi des liaisons infrarouges, souvent modulées vers 38 kHz comme les récepteurs du commerce. Raison de plus pour choisir une porteuse distincte, et pour coder l'émission : une séquence pseudo-aléatoire propre au robot donne une réjection par corrélation contre les autres émetteurs de la salle
- Impulsions à fort courant crête plutôt qu'un continu tiède : le rapport cyclique faible autorise des pointes bien au-delà du courant moyen admissible

#### Réception et suppression du continu

BPW77 / BPY 62, ou photodiode + TIA

- Couplage alternatif entre le détecteur et l'étage de gain, ou asservissement qui annule le continu. C'est le geste décisif : il rend la dynamique disponible pour le signal utile
- Le phototransistor échange gain contre bande passante par sa résistance de charge. Vérifie la bande atteinte à la charge retenue avant de figer la porteuse — c'est ce compromis, pas le composant, qui plafonne
- Si tu veux monter la porteuse plus haut, une photodiode suivie d'un amplificateur transimpédance lève la contrainte, au prix d'un composant actif de plus

#### Démodulation dans le firmware

ADC3 dédié · DMA · Cortex-M7

- Échantillonne à quatre fois la porteuse, déclenché par le même timer que l'émetteur : la démodulation I/Q se réduit alors à multiplier par des ±1, donc à des additions et soustractions
- Module = √(I² + Q²) : la mesure devient insensible à la phase, donc au temps de vol et aux dérives
- Le gain de traitement vient du rétrécissement de bande : passer de 20 kHz de bruit d'entrée à 200 Hz en sortie de filtre vaut un facteur dix en rapport signal sur bruit, gratuitement
- À 20 kHz de porteuse, cela fait 80 kéch/s sur une voie — négligeable pour un M7 à 550 MHz

Conséquence sur l'architecture

Cette voie ne peut pas se contenter d'un rang dans le balayage à 2 kHz de la barrette : elle réclame une conversion continue et rapide, synchronisée sur l'émetteur. ADC3 lui est donc dédié, en conversion continue déclenchée par timer avec DMA circulaire, et la surveillance lente — VBAT et les retours de courant — rejoint le balayage d'ADC1 et ADC2 sur PC0 et PC1, qui acceptent les trois convertisseurs. Répartition à confirmer sous CubeMX.

### Trois stations identiques

Avec un mètre de portée, la même chaîne couvre les trois visées : plus aucun bus I²C dans la boucle critique, une seule discipline de mesure à maîtriser, des cadences homogènes et une seule empreinte à valider. Le point de vigilance qui subsiste est que la mesure reste une intensité et non une distance : le seuil de déclenchement de l'esquive dépendra de l'albédo du cube, que le règlement ne garantit pas — il promet seulement qu'il sera « visible » en infrarouge. Les essais libres avant chaque phase servent précisément à l'étalonner contre le vrai obstacle.

Deux réserves indépendantes du traitement

Approvisionnement. L'OPV302 est un TT Electronics/Optek, les BPW77NA, BPW77NB et BPY 62 des Vishay en boîtier traversant. Aucun des trois n'est probablement dans la bibliothèque JLCPCB : prévois une pose manuelle sur une carte par ailleurs assemblée. Six composants traversants à souder soi-même, c'est une demi-heure — et le boîtier TO-46 sur pattes cintrées est de toute façon plus facile à orienter à la main qu'à faire poser par une machine.

Sécurité oculaire, et où se situe vraiment le risque. L'absence de collimation aide moins que l'intuition ne le suggère, parce que la classification se mesure à travers une ouverture normalisée de l'ordre de la pupille, à cent millimètres. Or un faisceau de 4° fait précisément 7 mm de diamètre à cette distance : il entre en entier. C'est ce qui sépare ce composant d'une LED infrarouge ordinaire, dont les 40 à 60° d'ouverture ne laissent passer qu'un pourcent de l'émission dans une pupille.

Distance | Diamètre du faisceau | Fraction dans une pupille de 7 mm
100 mm | 7 mm | la quasi-totalité
200 mm | 14 mm | 25 %
500 mm | 35 mm | 4 %
1 m | 70 mm | 1 %
3 m | 210 mm | 0,1 %

La lecture est donc l'inverse de ce que j'avais écrit : au bord de piste, à trois mètres, il ne reste que des microwatts et personne ne risque rien. Le danger est sur l'établi, à dix ou vingt centimètres, quand tu te penches sur le robot pour régler l'inclinaison — à 850 nm, invisible, sans réflexe de clignement, et sur une durée qui se compte en minutes. Prends l'habitude de n'alimenter les diodes qu'après l'armement, ce que la machine à états de départ permet déjà, et de travailler avec une caméra plutôt que l'œil quand tu vérifies la visée.

Sur la classe elle-même, reste prudent : la fiche technique que j'ai lue ne l'énonce pas, les distributeurs annoncent 3B, et 1,5 mW à 850 nm situe le composant autour de deux fois la limite de classe 1. Ce qui est certain, c'est que ce n'est pas de la classe 1. Et le mode impulsionnel n'arrange rien : les 12,6 mW crête sont évalués avec une correction qui pénalise les trains d'impulsions, donc la montée en fréquence durcit le dossier de sécurité pour un bénéfice nul.

### Le budget de broches analogiques

C'est la ressource rare de ce boîtier, et trois récepteurs la mettent exactement à niveau. Le LQFP100 n'expose que seize entrées ADC, et seules PC0 à PC3 sont câblées sur ADC3, le convertisseur qui doit servir la démodulation.

Usage | Voies | Broches | Convertisseur
Barrette de ligne | 12 | PA0–PA7, PB0, PB1, PC4, PC5 | ADC1 + ADC2, balayage à 2 kHz
Récepteurs de télémétrie | 3 | PC1 · PC2 · PC3 | ADC3 dédié, continu à 4 × la porteuse
Surveillance, derrière un mux 8:1 | 1 | PC0 | Rang ajouté au balayage ADC1/ADC2
Total | 16 / 16 | — | Aucune réserve analogique

Deux conséquences. VBAT et les deux retours de courant passent par un multiplexeur 74HC4051 : ce sont des signaux lents, les commuter ne coûte rien et cela libère les deux broches qui manquaient. Et il ne reste plus aucune marge — toute voie analogique supplémentaire imposerait le STM32H723ZGT6 en LQFP144, qui expose davantage d'entrées ADC3, au prix d'une carte plus grande.

Une erreur corrigée au passage : j'avais réservé une voie ADC pour la thermistance du pack. Elle n'a rien à y faire, sa place est sur l'entrée TS du BQ25887, qui gère lui-même la coupure thermique de charge.

### Séquence d'armement et de départ

Partir en passant la main devant le télémètre est confortable et évite de bousculer le robot au moment critique — mais c'est aussi le même capteur qui doit voir le cube, et n'importe quel spectateur passant devant déclencherait un départ. La séquence doit donc être verrouillée :

1. Armement par appui long sur le switch 5 directions, robot posé sur la piste. L'OLED affiche l'état, le buzzer confirme.
2. Armement de l'ESC : consigne à zéro maintenue deux secondes, attente des bips de l'ESC, turbine déclarée prête.
3. Champ libre : le télémètre avant doit lire « rien à moins de 400 mm » pendant trois secondes consécutives. Sans cette étape, une main déjà présente au moment de l'armement compte comme un départ.
4. Geste : objet détecté à moins de 100 mm pendant plus de 200 ms, puis retiré.
5. Compte à rebours sonore de deux à trois secondes, puis départ — et désactivation définitive de ce canal de déclenchement pour le reste de la tentative.

Ce que ça ne coûte pas

Le chronomètre ne se déclenche pas au démarrage du robot mais au moment où il coupe la barrière infrarouge de la ligne de départ, et il est placé entre la ligne d'arrivée et la ligne de départ. Le compte à rebours, la temporisation d'armement de l'ESC et la montée en régime de la turbine sont donc gratuits en temps. Prends-les larges plutôt que serrés.

§5

## Alimentation

Un pack 2S LiFePO4 délivre 6,4 V nominal, 7,3 V à pleine charge (3,65 V/cellule) et descend vers 5,0 V à vide. C'est parfait pour des moteurs 6 V attaqués directement, et c'est aussi ce qui rend la charge délicate : recharger du 2S depuis les 5 V de l'USB demande un chargeur élévateur, pas un abaisseur.

Fig. 4 — Le chargeur est placé avant l'interrupteur : le robot se recharge éteint. La ligne 3V3A est dérivée du 3,3 V par un filtre π, et non par un régulateur séparé, pour que la barrette et la référence ADC partagent exactement le même potentiel.

### Le chargeur

Le BQ25887 (C2761614, environ 1,90 $) est le composant qui rend l'ensemble simple : chargeur à découpage élévateur 2 A conçu pour charger un pack 2S depuis une entrée USB 5 V, avec équilibrage de cellules intégré, limite de courant d'entrée programmable et mesure de tension et de courant restituée en I²C. Cette dernière alimente directement l'affichage d'état de charge sur l'OLED.

Point de vigilance : sa tension de régulation par cellule descend jusqu'à 3,4 V, donc 3,60 V pour du LiFePO4 est atteignable — mais ce n'est pas sa valeur par défaut. Au reset, il part sur un profil Li-ion. Le firmware doit écrire VCELLREG avant d'autoriser la charge, et la broche CD doit maintenir le chargeur inhibé jusqu'à ce que cette écriture soit confirmée.

Si le BQ25887 venait à manquer, la solution de repli est un CH224K (C970725, 0,33 $) qui négocie 12 V en USB-PD, suivi d'un chargeur abaisseur LiFePO4 — au prix de l'obligation d'utiliser un chargeur PD et non un simple port USB.

### Ce que la turbine change au bilan

C'est l'ajout qui redimensionne tout le reste. Une turbine capable de produire un appui utile sur un robot de cette taille consomme entre 5 et 15 A en continu — davantage que les deux moteurs de traction réunis. Trois conséquences en cascade :

- Le pack change de catégorie. Un accu de réception 2S LiFePO4 de 450 mAh est hors sujet : il faut au minimum 1000 mAh avec un taux de décharge de 15 C, et le poids gagné en électronique se reperd là.
- La tension joue contre toi. Un 2S LiFePO4 plafonne à 7,3 V et travaille surtout vers 6,4 V, là où les ensembles ESC et moteur brushless du commerce sont calibrés pour du 2S LiPo à 8,4 V. La poussée réelle sera nettement inférieure à celle annoncée par le fabricant — vérifie-la avant de dimensionner la mécanique.
- L'appel de courant fait chuter VBAT. Une montée en régime brutale peut faire décrocher le convertisseur 3,3 V et redémarrer le MCU en pleine ligne droite. Rampe la consigne de turbine plutôt que de l'appliquer d'un coup, augmente le volume de condensateurs à l'entrée du buck, et surveille VBAT sur ADC3 pour lever une alarme avant le décrochage.

### Connectique et protections

- USB-C : embase TYPE-C-31-M-12 (C165948), 16 broches, avec les deux résistances de 5,1 kΩ sur CC1/CC2 — sans elles aucun chargeur ne délivre le 5 V. D+/D− remontent au MCU pour le DFU et le port série.
- Accu : XT30 ou JST-PH selon le courant crête retenu, plus une embase d'équilibrage JST-XH 3 points pour charger et mesurer les cellules à l'extérieur.
- Anti-inversion : MOSFET canal P en série côté haut, pas une diode — la chute de 0,4 V d'une Schottky à 3 A représente 1,2 W de perte pure.
- Écrêtage : à 3 m/s, un freinage à fond renvoie l'énergie cinétique dans un pack potentiellement plein. Prévois un TVS d'écrêtage vers 9 V sur VBAT et du volume de condensateurs, sinon c'est le buck ou le driver qui encaisse.

§6

## Affectation des broches

Proposition cohérente pour le LQFP100, à confirmer sous CubeMX — notamment le mapping exact des canaux ADC, qui diffère d'une déclinaison H7 à l'autre. Le point structurant : le H723 en LQFP100 n'expose que seize broches capables d'ADC. Douze vont à la barrette, quatre à la surveillance ; il n'en reste aucune, ce qui explique le choix de douze capteurs de ligne plutôt que seize.

Fonction | Périphérique | Broches | Notes
Barrette de ligne, 12 voies | ADC1 + ADC2, dual regular simultaneous + DMA | PA0–PA7, PB0, PB1, PC4, PC5 | Déclenché par TIM6, synchronisé sur les impulsions IR
Surveillance de bord | Mux 74HC4051 → rang ADC1/ADC2 | PC0 + 3 GPIO de sélection | VBAT, IPROPI1, IPROPI2 et réserves — signaux lents, une seule broche suffit
Télémètres analogiques | ADC3 dédié, continu + DMA | PC1 · PC2 · PC3 (réception) | Échantillonnage à 4 × la porteuse, synchronisé sur les émetteurs ; ADC3 ne partage rien
Émetteurs de télémétrie | Timer, multiplexés dans le temps | PB2 · PE2 · PC13 | Un seul actif à la fois : pas de diaphonie entre visées
PWM des deux ponts | TIM1 CH1–CH4 | PE9 · PE11 · PE13 · PE14 | Centré, 25 kHz, hors bande audible
Encodeur gauche | TIM3 mode encodeur | PB4 · PB5 | Filtre d'entrée activé
Encodeur droit | TIM8 mode encodeur | PC6 · PC7 | 16 bits, lu à 1 kHz
Drivers, service | GPIO | PD0, PD1 (nSLEEP) · PD3, PD4 (nFAULT) | nSLEEP rappelé au 0 V par 100 kΩ
OLED et chargeur | I2C2 400 kHz | PB10 · PB11 | Bus lent séparé, jamais sollicité en course
Centrale inertielle | SPI2 | PB12–PB15 | 10 MHz, interruption DRDY sur PE6
Flash de traces | SPI3 | PC10, PC11, PC12 · CS PD2 | SPI simple à 50 MHz suffit — pas besoin de QSPI
Module BLE | USART1 + GPIO | PA9 · PA10 · PA8 (EN) | PA8 commande le load switch d'alimentation
USB | USB OTG FS | PA11 · PA12 | Quartz HSE obligatoire pour l'horloge USB
Débogage | SWD + ITM | PA13 · PA14 · PB3 (SWO) | PB3 réservé au SWO, d'où l'abandon de TIM2
Bancs d'émetteurs IR | GPIO | PE7 · PE8 | Deux bancs alternés, anti-diaphonie
Buzzer | TIM17 CH1 | PB9 | Via MOSFET + diode de roue libre
Switch 5 directions | GPIO + EXTI | PE10, PE12, PE15, PD10, PD13 | Haut / bas / gauche / droite / appui, commun à la masse
Départ | GPIO + EXTI | PD14 (bouton et jack) | Moyen conforme au règlement, en parallèle du départ par télémètre
ESC de turbine | TIM4 CH3 (+ DMA si DShot) | PB8 | Broche BEC de l'embase laissée non connectée
LED d'état | GPIO | PD15 · PC8 · PC9 | Dont une dédiée « BLE alimenté », visible du jury
Horloge | HSE | PH0 · PH1 | Quartz 25 MHz

Bilan : environ 72 broches affectées sur 82. Les seize entrées analogiques, elles, sont saturées — c'est là qu'est la vraie limite, pas sur le nombre d'E/S. L'abandon du bus I²C des télémètres libère PB6 et PB7, qui rejoignent les réserves avec PD7–PD9, PE3–PE5, PC14 et PC15, à sortir sur pastilles de test.

§7

## Nomenclature JLCPCB

Les références marquées vérifiées ont été contrôlées en stock LCSC/JLCPCB le 30 août 2026. Les prix et les stocks bougent vite : refais un passage juste avant de figer la nomenclature, et prévois systématiquement une deuxième source pour les pièces critiques.

Fonction | Référence | JLCPCB | Qté | État
Microcontrôleur | STM32H723VGT6 · LQFP100 | C730142 | 1 | vérifié
Pont en H | DRV8874PWPR · HTSSOP-16 | C1855818 | 2 | vérifié · 0,77 $
Émetteurs de télémétrie | OPV302 · VCSEL 850 nm, TO-46 lentille dôme | — | 3 | pose manuelle
Récepteurs de télémétrie | BPW77NA / BPW77NB / BPY 62 | — | 3 | pose manuelle
Multiplexeur de surveillance | 74HC4051 · 8:1 analogique | — | 1 | à vérifier
Centrale inertielle | LSM6DSOTR | C2655100 | 1 | vérifié · 2,42 $
IMU — variante économique | QMI8658C | C2842151 | 1 | vérifié · 0,74 $
Capteur réflectif | ITR8307/S17/TR8(B) | C81632 | 12 | vérifié · 0,06 $
Chargeur 2S élévateur | BQ25887RGER · VQFN-24 | C2761614 | 1 | vérifié · 1,90 $
Convertisseur 3,3 V | TPS62933DRLR · SOT583 | C3200405 | 1 | vérifié · 0,24 $
Embase USB-C | TYPE-C-31-M-12 | C165948 | 1 | vérifié
Sink USB-PD (repli chargeur) | CH224K | C970725 | 1 | vérifié · 0,33 $
Flash de traces | W25Q128JVSIQ · SOIC-8 | — | 1 | à vérifier
Protection USB | USBLC6-2SC6 | — | 1 | à vérifier
MOSFET commutation | AO3400A (N) · SI2301 (P) | — | 6 | à vérifier
Buzzer passif | magnétique CMS 9 × 5,5 mm | — | 1 | à vérifier
Switch 5 directions | TS-006 · 5 voies + commun | C3674 | 1 | empreinte à confirmer
Embase ESC turbine | barrette 1×3 au pas de 2,54 mm | hors PCBA | 1 | broche centrale NC
Quartz HSE | 25 MHz · 3225 · 10 ppm | — | 1 | à vérifier
Connecteur de debug | Tag-Connect TC2050-IDC-NL | aucun | 0 | empreinte seule
Afficheur | module OLED SSD1306 0,96″ I²C | hors PCBA | 1 | embase 4 points
Module BLE | HM-11 / JDY-08 ou ESP32-C3-MINI-1 | hors PCBA | 1 | embase 6 points

Le microcontrôleur devient le poste dominant, ce qui est le signe d'une nomenclature saine. Les six composants de télémétrie sont traversants et se posent à la main après l'assemblage : leur absence de la bibliothèque JLCPCB ne bloque donc pas la commande.

§8

## Ce que tu as oublié

Trente-sept points relevés, classés par ce qu'ils te coûtent si tu les laisses passer. Le premier concerne directement le connecteur de la capture que tu m'as envoyée ; le second, ton idée de départ par télémètre.

Bloquant Fiabilité Chrono

### Bloquant

- 01

##### Ton connecteur TC2030 n'a ni VTref ni SWO

  Sur la capture, les six broches sont RXD, TXD, RST, SWD-CLK, SWD-IO, GND. Il manque VTref : une sonde ST-Link mesure la tension de la cible sur cette broche pour adapter ses niveaux, et refuse de se connecter si elle lit 0 V. Il manque aussi SWO, qui est la sortie de trace ITM — c'est-à-dire exactement le canal de debug que tu cherches. Six broches ne suffisent pas pour SWD + UART + VTref + SWO. Deux issues : passer au TC2050-IDC-NL (2×05, même famille, même encombrement) et tout loger ; ou garder le TC2030 avec le brochage standard ARM — 1 VTref, 2 SWDIO, 3 NRST, 4 SWCLK, 5 GND, 6 SWO — et déporter l'UART sur le port BLE, qui joue déjà ce rôle.
- 02

##### Le départ par geste n'est pas dans la liste du règlement

  Le chapitre 2 énumère trois moyens : « par interrupteur, un bouton poussoir ou par un jack ». Un geste devant un télémètre n'y figure pas, et l'énumération se lit comme limitative. Ton idée est bonne à l'usage — elle évite de bousculer le robot au moment le plus sensible — mais elle t'expose à un jury tatillon. Deux précautions qui ne coûtent rien : garde un bouton START physique câblé et fonctionnel comme moyen de départ conforme, et pose la question aux organisateurs avant la compétition, l'adresse figure en première page du règlement. La séquence verrouillée décrite au §4 gère le reste : faux départs, armement de l'ESC, et un compte à rebours qui ne te coûte aucun temps puisque le chrono ne part qu'à la barrière infrarouge.
- 03

##### L'état des drivers au reset n'est pas défini

  Entre la mise sous tension et l'initialisation du firmware, les GPIO du STM32 sont en entrée haute impédance. Sans rappel externe, nSLEEP et les entrées PWM flottent et le robot peut partir tout seul sur l'établi. Résistance de 100 kΩ vers la masse sur nSLEEP et sur chaque entrée de pont — c'est trois composants qui évitent un doigt écrasé.
- 04

##### Les résistances CC de l'USB-C

  Deux résistances de 5,1 kΩ entre CC1/CC2 et la masse. Sans elles, un chargeur USB-C ne voit aucun périphérique et ne délivre rien du tout. C'est l'oubli le plus fréquent sur une première carte USB-C, et il ne se voit qu'au moment où rien ne charge.
- 05

##### Le module BLE détachable règle la conformité, pas la fiabilité

  Le chapitre 2 exige que les moyens de communication soient inhibés au moment du départ. Un module qu'on retire physiquement est la démonstration la plus simple qui soit devant un jury — bien meilleure qu'une désactivation logicielle. Garde quand même le load switch à MOSFET canal P et sa LED témoin : ils te permettent de laisser le module en place entre deux essais et de le couper à la volée, sans manipuler la carte à chaque tentative. Et ils couvrent le cas où tu oublies de le retirer.
- 06

##### L'interrupteur marche/arrêt facile d'accès

  Exigé explicitement par le règlement, et distinct du connecteur d'accu. Un interrupteur à glissière 5 A dans la ligne batterie, accessible robot posé sur ses roues, avec limitation d'appel de courant (MOSFET canal P à montée lente ou CTN) — sinon l'étincelle à chaque enclenchement usera le contact et fera redémarrer le MCU en boucle.
- 07

##### Le robot ne peut pas voir l'arrivée

  Les marques sont à 40 mm à droite de l'axe de piste et font 19 mm de large : elles occupent la bande +30,5 à +49,5 mm. Une barrette centrée de 60 mm de large ne les voit jamais, et le robot ne sait donc pas quand freiner. Or il doit s'arrêter en moins d'un mètre après l'arrivée, sous peine d'essai invalidé. D'où la couverture ±55 mm retenue au §4.
- 08

##### La référence analogique et son retour de masse

  Douze voies ADC en 16 bits à côté de deux ponts en H qui hachent plusieurs ampères à 25 kHz : sans plan de masse analogique dédié, sans filtre π sur VDDA et sans VREF+ propre, tu mesureras le bruit des moteurs. Et alimente la barrette depuis 3V3A : la mesure devient ratiométrique et l'ondulation du buck disparaît du résultat.

### Fiabilité

- 09

##### Le BEC de l'ESC peut emporter toute la carte

  La plupart des ESC brushless renvoient 5 ou 6 V de BEC sur le fil central du connecteur servo. Câblé sur une embase où cette broche rejoint le 3,3 V, il détruit le MCU, l'IMU, les télémètres et l'écran d'un seul coup. Laisse la broche centrale non connectée, marque-la « NC » en sérigraphie, et n'utilise que signal et masse. Si tu veux vraiment récupérer le BEC un jour, fais-le passer par un cavalier explicite vers un rail 5 V séparé.
- 10

##### L'ESC ne s'arme pas tout seul

  Un ESC standard exige un signal à gaz zéro pendant une à deux secondes après sa mise sous tension, sinon il refuse d'armer et reste muet. Cette temporisation doit faire partie de la séquence de pré-départ, pas du démarrage du firmware — sinon tu découvriras au bord de piste que la turbine ne part pas. Ses bips d'armement vont par ailleurs se mélanger aux tiens : prévois-le dans le protocole sonore. Le DShot supprime le problème et donne en prime le régime réel en retour, ce qui permet de détecter un décrochage de turbine.
- 11

##### Le télémètre de départ est aussi celui qui voit le cube

  Un seul capteur pour deux rôles antagonistes : entre l'armement et le départ, n'importe quel spectateur passant devant déclenche le robot. D'où la machine à états du §4, avec sa fenêtre de champ libre obligatoire avant d'accepter un geste, et surtout la désactivation définitive de ce canal dès le départ donné — sinon le cube lui-même relancerait un événement de départ en pleine course.
- 12

##### Un module détachable doit être retenu et détecté

  Un module BLE qui se déclipse à 3 m/s finit sur la piste, et le règlement n'aime pas les pièces qui se détachent. Choisis une embase à verrouillage, ou ajoute une vis. Et câble une broche de présence : le firmware doit savoir si le module est là, pour ne pas passer son temps à attendre des réponses UART qui ne viendront jamais.
- 13

##### Distinguer un croisement d'une marque

  Tourner à un croisement invalide l'essai. Les deux motifs sont noirs et perpendiculaires ; ce qui les sépare, c'est l'étendue latérale — toute la barrette pour un croisement, le seul quart droit pour une marque. La barrette symétrique n'est donc pas un luxe, c'est ce qui rend la discrimination possible.
- 14

##### Le freinage renvoie de l'énergie dans le pack

  Freiner de 3 m/s à l'arrêt en moins d'un mètre, avec des ponts en H en mode frein, transforme les moteurs en générateurs. Si le pack est plein, la tension de bus monte. Prévois un écrêteur TVS vers 9 V sur VBAT et un volume de condensateurs suffisant — sinon c'est le TPS62933 ou un DRV8874 qui absorbe la surtension, une fois.
- 15

##### Le BQ25887 démarre sur un profil Li-ion

  Ses valeurs par défaut visent du Li-ion. Appliquées à du LiFePO4, elles chargent au-delà de 4 V par cellule. Le firmware doit écrire VCELLREG à 3,60 V avant toute charge, et la broche CD doit maintenir le chargeur inhibé tant que cette écriture n'est pas relue et confirmée. Prévois aussi la CTN sur le pack pour l'entrée TS, ou le pont de résistances qui la neutralise.
- 16

##### La jauge de batterie par tension ne marche pas en LiFePO4

  La courbe de décharge du LiFePO4 est extrêmement plate : entre 90 % et 20 % de charge, la tension bouge de quelques dizaines de millivolts, noyés dans la chute due au courant moteur. Il faut intégrer le courant — ce que permettent les sorties IPROPI des drivers et le shunt d'entrée. Sans ça, tu ne sauras jamais s'il te reste un tour.
- 17

##### Les circuits de protection 2S du commerce sont calibrés Li-ion

  Les PCM courants (type HY2120) coupent en surtension vers 4,25 V et en sous-tension vers 2,4 V par cellule : ces seuils n'ont aucun sens pour du LiFePO4, dont la plage utile est 2,5–3,65 V. Achète un pack dont le PCM est réellement prévu pour du LiFePO4, ou traite la sous-tension côté firmware avec une coupure et une alarme sonore.
- 18

##### Chien de garde et état de repli

  Un robot qui plante à 3 m/s finit dans les gradins. Active l'IWDG, et fais en sorte que le HardFault comme le débordement de watchdog forcent nSLEEP à 0 avant tout redémarrage. Lis nFAULT des drivers et traite-le : surintensité, surchauffe et sous-tension y remontent.
- 19

##### Tu n'avais pas prévu de mesurer le courant moteur

  C'est gratuit avec le DRV8874 — une résistance sur IPROPI et une voie ADC — et ça donne trois choses : la détection de calage, une image directe du couple pour l'antipatinage, et la coulométrie du point précédent.
- 20

##### L'empreinte Tag-Connect « FP » traverse la carte

  La variante à pattes de positionnement exige trois trous non métallisés traversants et une zone d'exclusion des deux côtés du PCB — pas seulement en face avant. Réserve aussi le dégagement mécanique en dessous : les pattes dépassent sous la carte, et un composant placé là empêche le câble de se clipser.
- 21

##### Le filtrage des moteurs

  Un moteur à charbons est un générateur d'impulsions large bande. 100 nF X7R aux bornes de chaque moteur, fils d'alimentation torsadés, et retour de masse puissance ramené en étoile au point d'entrée batterie — pas à travers le plan analogique. Sinon le hachage remonte dans les ADC et fait planter le bus I²C des télémètres.
- 22

##### La thermique du DRV8874

  200 mΩ à 3 A continus font près de 2 W par pont. Le pad thermique doit être cousu de vias vers un plan de cuivre, et pas posé sur un îlot isolé — sinon la protection thermique coupera le moteur en fin de ligne droite, au pire moment.
- 23

##### Le connecteur d'équilibrage

  Une embase JST-XH 3 points sur les points milieux du pack permet de charger avec un chargeur externe, de mesurer chaque cellule et de rattraper un déséquilibre. Le règlement autorise le changement de batterie en échange standard pendant les trois minutes : prévois donc au moins deux packs et une connectique détrompée.
- 24

##### Protection ESD, et l'inclinaison qui ne doit pas bouger

  USBLC6-2SC6 sur D+/D− et sur VBUS, et la fiche technique de l'OPV302 signale explicitement sa sensibilité aux décharges : protège aussi la ligne de commande. Côté mécanique, l'inclinaison de 4° est désormais un paramètre de conception à part entière, et elle tient sur des pattes cintrées : un choc en essais libres la dérègle sans que rien ne casse ni ne se voie. Prévois une butée ou une goutte de colle après réglage, et une routine de vérification de portée dans le menu OLED pour t'en apercevoir au stand plutôt qu'en course.

### Chrono

- 25

##### L'appui aérodynamique reste la contrainte dominante

  Tu as bien fait de prévoir la turbine : dans un virage de 20 cm de rayon, 2,5 m/s demandent 3,2 g de force latérale, et aucun pneu de robot ne fournit ça sur une bâche. Mais garde en tête que c'est un système à part entière, pas un accessoire — il a sa propre séquence d'armement, son propre budget d'énergie, et il déplace le centre de gravité. Traite-le comme un second actionneur, avec sa consigne dans la boucle de contrôle : l'appui n'a d'intérêt qu'en virage, et le faire tourner à fond en ligne droite ne fait que vider le pack.
- 26

##### La turbine redimensionne le pack

  Cinq à quinze ampères en continu, soit plus que les deux moteurs réunis. Un accu de réception 2S LiFePO4 de 450 mAh est hors sujet : vise 1000 mAh et 15 C au minimum. Et le 2S LiFePO4 plafonne à 7,3 V là où les ensembles ESC et brushless du commerce sont calibrés pour du 2S LiPo à 8,4 V : la poussée réelle sera inférieure à celle du catalogue. Mesure-la avant de figer la mécanique, pas après.
- 27

##### Le couple disponible plafonne ton chrono avant l'électronique

  Un GM12-N20 1:30 sous 6 V tourne autour de 1000 tr/min, soit environ 1,4 m/s avec des roues de 27 mm. Sur une ligne droite de 6 m, c'est très loin du potentiel. Si tu vises 2,5 m/s, il faut un rapport plus court ou des roues plus grandes, et alors le courant grimpe : le DRV8874 (6 A crête) et le pack doivent suivre, avec une capacité de décharge d'au moins 15 C.
- 28

##### Les encodeurs ne détectent pas le dérapage

  C'est le point le plus contre-intuitif de ton cahier des charges. Quand les deux roues glissent ensemble, l'odométrie reste parfaitement cohérente — et fausse. Il faut une référence indépendante des roues : le gyroscope, dont le lacet mesuré est comparé au lacet odométrique (vd − vg)/e. L'écart est le dérapage. Encore mieux si tu veux la vitesse sol réelle : un capteur de flux optique (PMW3901) sous le châssis — à valider côté stock JLCPCB.
- 29

##### L'inclinaison plafonne la portée avant, et les 48 mA sont hors d'atteinte

  Deux lignes de la fiche technique se combinent contre la visée avant. L'inclinaison qui protège du sol fait monter le faisceau de 35 mm par mètre : au-delà d'environ un mètre, il passe au-dessus d'un cube de 100 mm. Et le mode 48 mA n'est spécifié que pour des impulsions de 1 µs à 10 % de rapport cyclique — inaccessible sous une porteuse à 20 kHz, dont la période haute dure 25 µs. Raccourcir les impulsions et monter à 100 kHz le débloquerait, mais pour rien : les deux régimes délivrent exactement 1,26 mW de puissance moyenne, et c'est elle seule que voit un détecteur synchrone. Le seul levier de portée qui reste est la surface du récepteur, et c'est aussi le seul qui n'aggrave pas le dossier de sécurité.
- 30

##### Trois émetteurs IR pulsés dans une salle qui en est déjà pleine

  Les barrières de chronométrage des organisateurs sont des liaisons infrarouges, souvent modulées vers 38 kHz comme les récepteurs du commerce, et chaque concurrent arrive avec ses propres émetteurs. Trois raisons de ne pas choisir sa porteuse au hasard : reste à l'écart de 38 kHz, code l'émission avec une séquence propre au robot pour obtenir une réjection par corrélation, et vérifie en essais libres que tu ne perturbes pas le chronométrage — un essai invalidé pour cette raison serait cher payé.
- 31

##### La visée du télémètre gauche décide la Q1

  Le mur fait 10 cm de haut et se trouve à 15 cm à gauche du centre virtuel de la piste absente. C'est la visée la plus facile des trois : à 150 mm, le faisceau incliné de 4° n'est monté que de 10 mm et la tache fait 10 mm, largement dans la cible. Tout le budget d'inclinaison est donc dicté par la visée avant, pas par celle-ci. Et comme la piste manque sur tout un virage à 20 cm de rayon, il faut une odométrie propre pour tenir la trajectoire entre deux mesures.
- 32

##### L'apprentissage du circuit, autorisé et rentable

  Le règlement dit explicitement que le robot peut mémoriser le tracé. C'est le plus gros levier de chrono du concours : au tour d'apprentissage on relève courbure et distance, puis on calcule un profil de vitesse qui freine avant le virage plutôt que dedans. Cela suppose une mémoire non volatile qui survit au changement de batterie, d'où la flash SPI.
- 33

##### Le BLE ne suffira pas pour les traces

  Vingt signaux à 1 kHz en 16 bits représentent 40 ko/s. Le BLE en délivre quelques-uns. La chaîne réaliste est : enregistrement en flash SPI pendant la tentative, puis vidage par USB CDC entre deux essais. Le BLE reste utile pour la supervision légère et les réglages, pas pour le log.
- 34

##### La hauteur de la barrette doit être réglable

  L'ITR8307 travaille au mieux entre 2 et 4 mm de la surface. Sur une bâche qui ondule, c'est peu — et si les capteurs sont sur la carte mère, cette hauteur n'est plus réglable du tout. Deux compensations, et elles sont indépendantes du PCB. La première est mécanique : des entretoises sur mesure sous le support moteur portent l'axe à la hauteur voulue — 4 mm avec les roues Pololu 40 mm retenues. La seconde est logicielle : un courant d'émetteur piloté rattrape une hauteur résiduelle trop grande. Usine un premier jeu d'entretoises et mesure la garde au sol réelle avant de router.
- 35

##### Prévois une voie « ambiante seule » dans chaque cycle

  Le chapitre 10 annonce un éclairage non uniforme et variable. La mesure émetteurs éteints, soustraite de la mesure éclairée, rend le capteur indifférent à l'ambiante — et son niveau brut te dit en plus si tu passes sous un projecteur, information exploitable pour resserrer les seuils.
- 36

##### Masse et centre de gravité

  La batterie est la masse dominante. Placée au-dessus de l'essieu moteur, elle charge les roues motrices et améliore l'adhérence ; placée à l'avant, elle allège la traction et fait sous-virer. Décide-le au niveau de l'implantation du PCB, pas après — le connecteur d'accu et le pack doivent avoir leur place réservée dès le placement.
- 37

##### L'étalonnage du diamètre de roue

  L'usure et le nettoyage des pneus, autorisés pendant les tentatives, changent le diamètre effectif de quelques pourcents. Toute l'odométrie et la carte apprise en dépendent. Prévois une routine d'étalonnage dans le menu OLED : le robot roule une distance connue, tu corriges le facteur d'échelle.

§9

## Prochaines étapes

Dans cet ordre, parce que chaque étape verrouille des choix pour la suivante.

1. Figer la motorisation et la turbine ensemble. Vitesse cible, rapport de réduction, diamètre de roue, courant crête de traction, et poussée d'appui mesurée sous 6,4 V et non sous 8,4 V. C'est ce trio qui dimensionne le pack, les drivers et les pistes de puissance — tout le reste en découle.
2. Écrire aux organisateurs au sujet du départ par télémètre. La réponse arrive vite et décide si le bouton START reste un secours ou devient le moyen principal.
3. Valider le brochage sous CubeMX. Le mapping exact des canaux ADC est le seul point du §6 qui peut te réserver une surprise : vérifie que les douze voies de la barrette tombent bien sur ADC1 et ADC2, et les quatre de surveillance sur ADC3.
4. Usiner un premier jeu d'entretoises et mesurer la garde au sol réelle, roues et supports moteurs montés. Le calcul annonce 4 mm d'entretoises pour 5 mm de garde ; c'est la mesure qui tranche, et c'est elle qui valide la barrette de ligne sur la carte mère.
5. Prototyper les deux chaînes optiques séparément. D'un côté trois ou quatre ITR8307 balayés en hauteur de 2 à 8 mm, avec la soustraction numérique en place. De l'autre une station OPV302 + BPW77 sur plaque d'essai, pour caler la porteuse, la constante de couplage alternatif et le gain, et mesurer la portée réelle contre un cube et contre un mur. Ce sont les deux inconnues du projet, et elles ne se valident pas ensemble.
6. Trancher le connecteur de debug. TC2050 en 2×05, ou TC2030 rebroché en VTref / SWDIO / NRST / SWCLK / GND / SWO. Ce choix conditionne la place autour et n'est plus modifiable après le routage.
7. Refaire un passage stock JLCPCB juste avant de commander, et remplir les références marquées « à vérifier » au §7.

Sur la disponibilité

Les références et prix vérifiés le sont à la date de ce document. La pièce la plus exposée à une rupture est le STM32H723VGT6 ; garde en tête que le STM32H750VBT6 est une roue de secours pin-compatible en LQFP100, au prix d'une flash interne réduite à 128 Ko — ce qui rend la flash SPI externe obligatoire au lieu d'optionnelle.

Sources vérifiées le 30 août 2026 — jlcpcb.com/partdetail (STM32H723VGT6 C730142, DRV8874PWPR C1855818, CH224K C970725) · lcsc.com (LSM6DSOTR C2655100, BQ25887RGER C2761614, ITR8307/S17/TR8(B) C81632, TPS62933DRLR C3200405, TYPE-C-31-M-12 C165948) · ti.com/lit/ds/symlink/bq25887.pdf · st.com — datasheet STM32H723VG DS13313 · ttelectronics.com — datasheet OPV302 Rev C 09/2018 · Règlement TNRS Formule 1 v2.11, F. Giamarchi et J.-R. Vaillé.

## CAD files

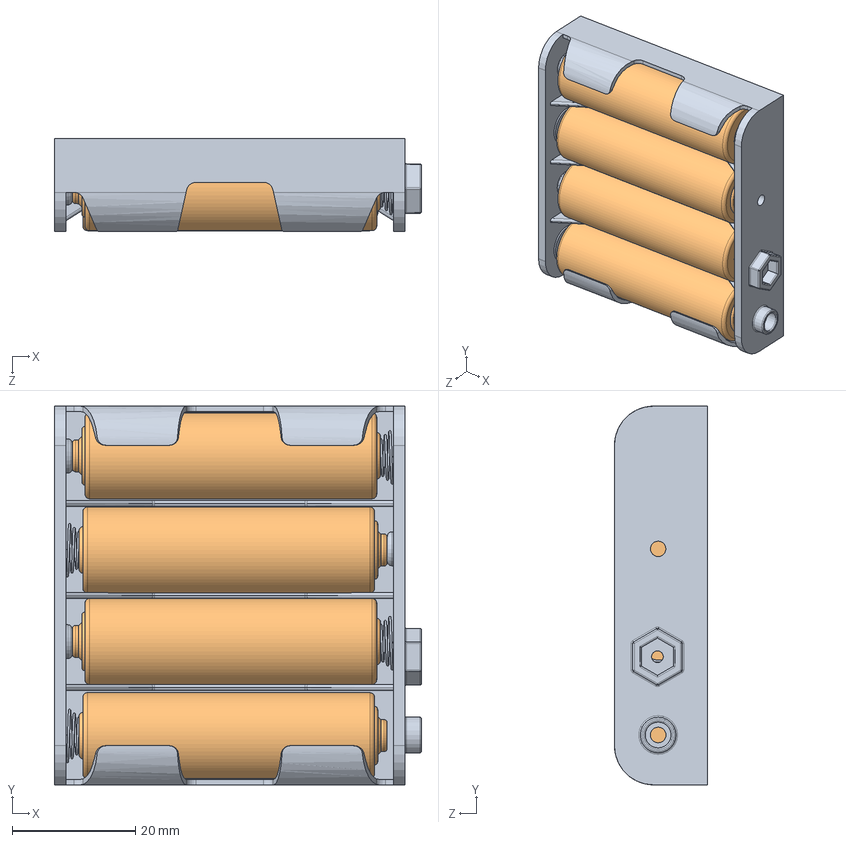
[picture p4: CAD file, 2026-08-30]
mechanics/battery-holder-4xaa-1.snapshot.1/Batterie nel portabatterie.SLDASM
59.6 x 61.5 x 15.1 mm
User Library-R6_AA_UM3-1_5V_holder4AA
Batteria ricaricabile stilo x 4

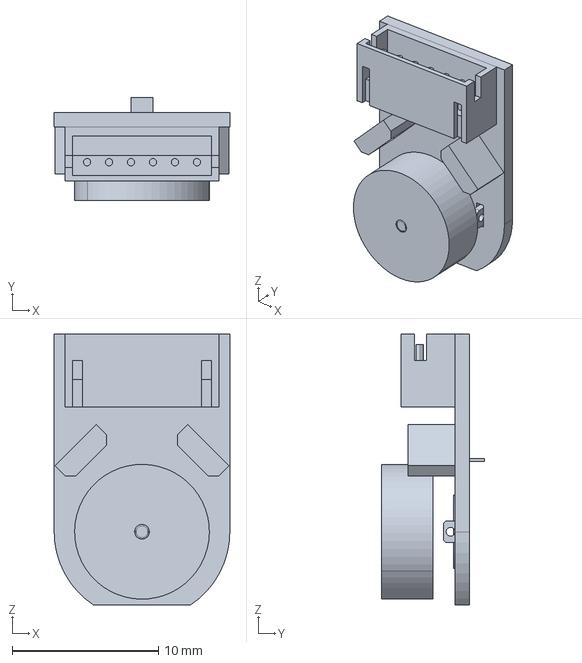
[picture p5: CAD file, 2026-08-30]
electronics/kicad-lib/3d/GM12-N20_motor_encoder.step
12.0 x 7.00 x 18.5 mm

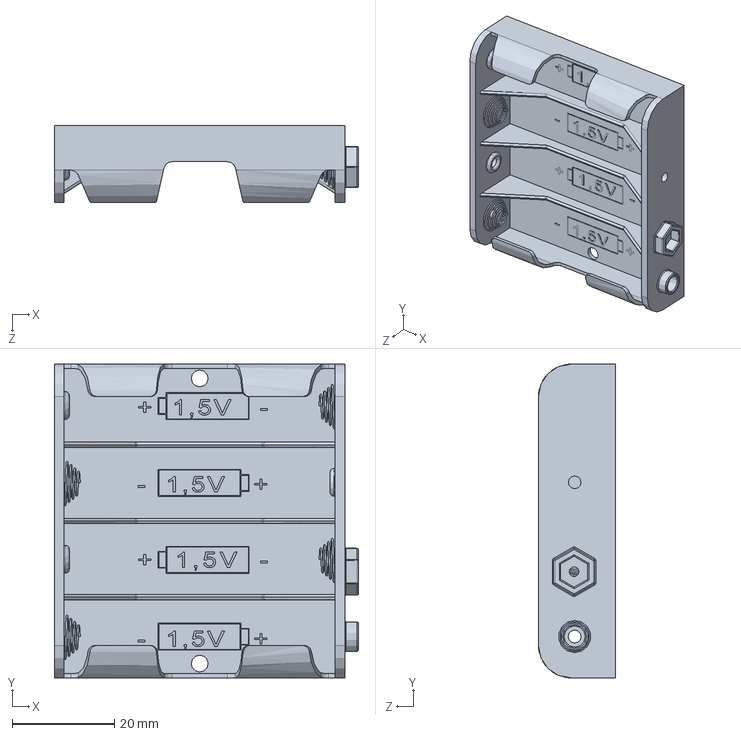
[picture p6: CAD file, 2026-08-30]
mechanics/battery-holder-4xaa-1.snapshot.1/User Library-R6_AA_UM3-1_5V_holder4AA.SLDPRT
59.6 x 61.5 x 15.1 mm

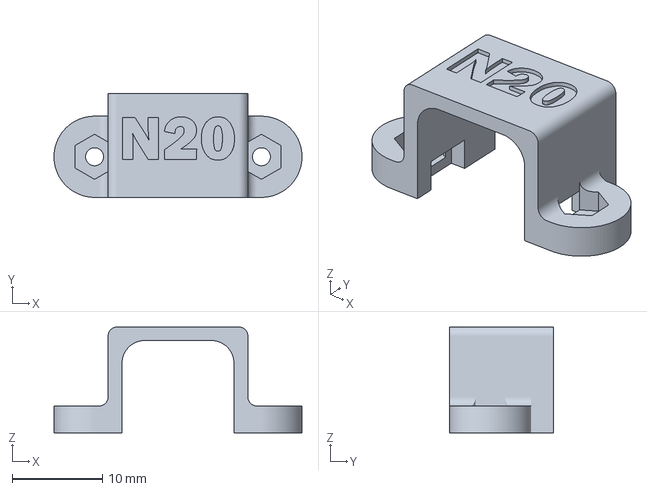
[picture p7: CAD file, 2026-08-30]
mechanics/motorHolder.fcstd
27.5 x 11.5 x 11.8 mm

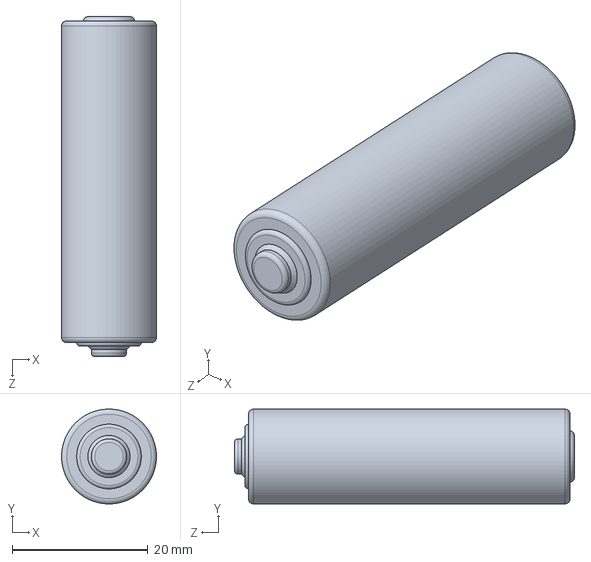
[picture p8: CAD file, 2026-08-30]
mechanics/battery-holder-4xaa-1.snapshot.1/Batteria ricaricabile stilo.SLDPRT
14.0 x 14.0 x 50.0 mm

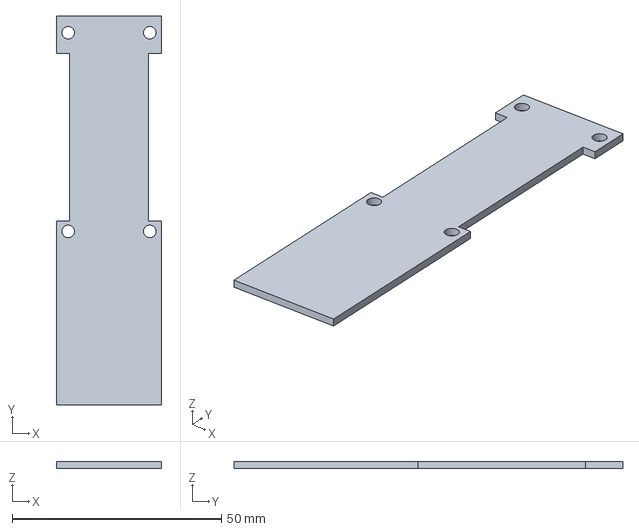
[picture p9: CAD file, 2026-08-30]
mechanics/CarteMere.fcstd
25.0 x 93.0 x 1.60 mm

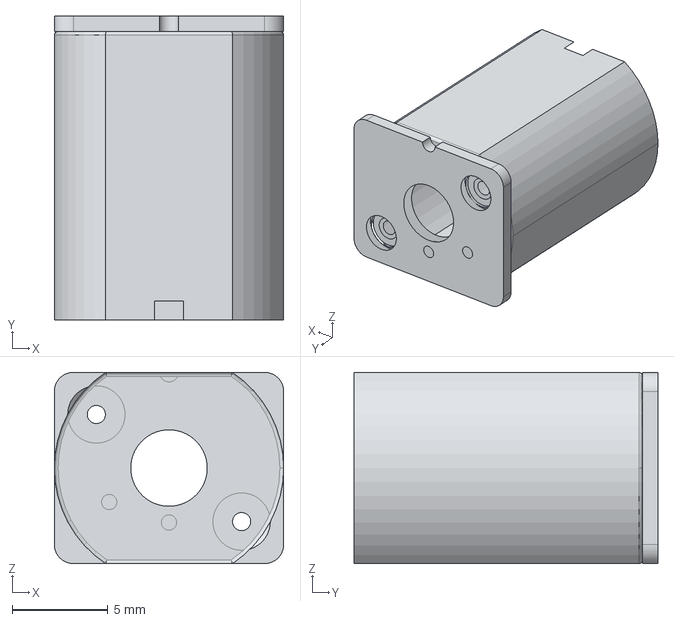
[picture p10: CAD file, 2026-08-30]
electronics/kicad-lib/3d/GM12-N20_motor_can.step
12.0 x 15.9 x 10.0 mm

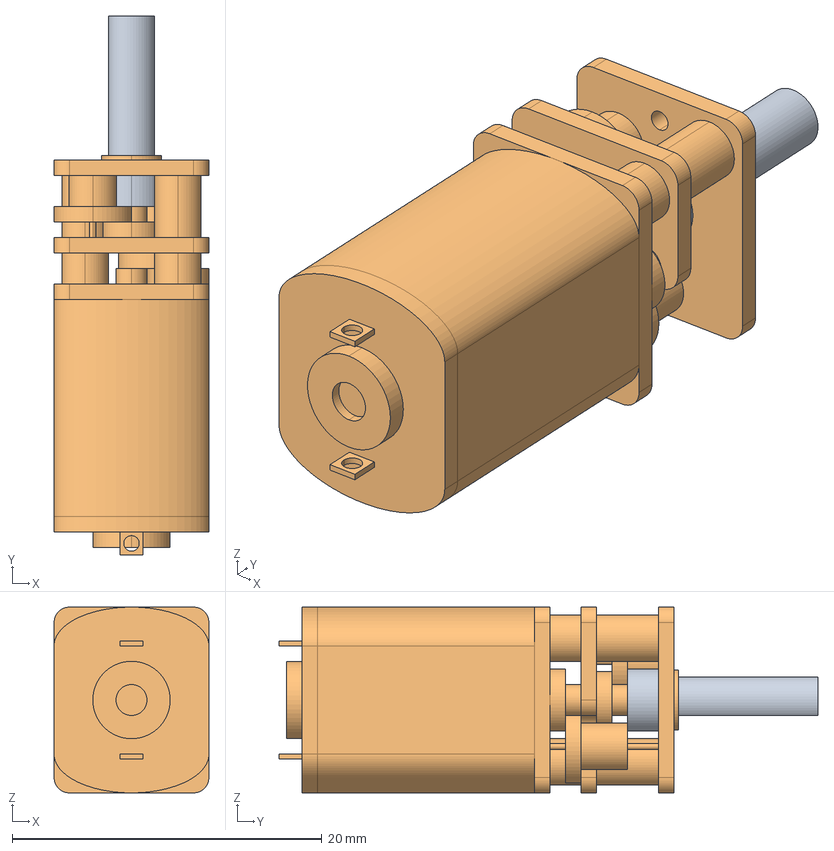
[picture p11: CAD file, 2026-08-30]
mechanics/motorM20.fcstd
10.0 x 34.8 x 12.0 mm
Brazo_M_STEP1_01
Motor STEP

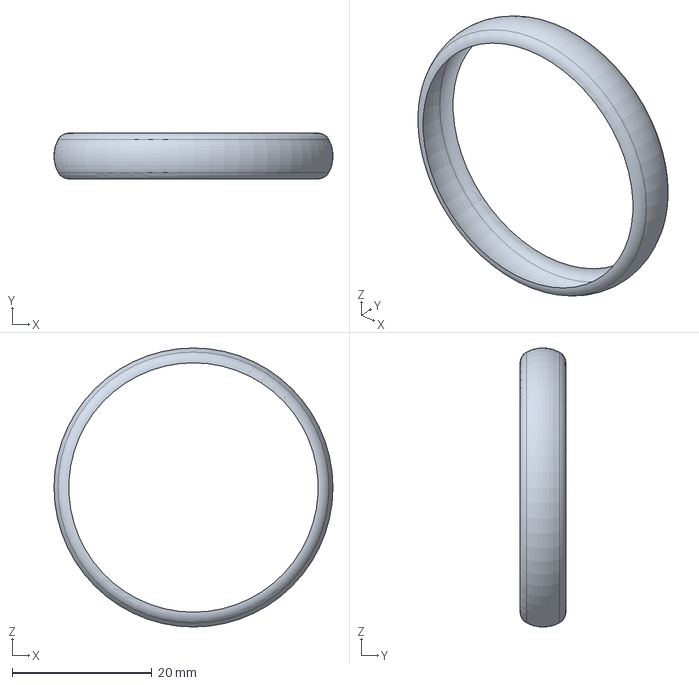
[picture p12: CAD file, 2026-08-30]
electronics/kicad-lib/3d/Pololu_wheel_40x7_tire.step
40.0 x 6.55 x 40.0 mm

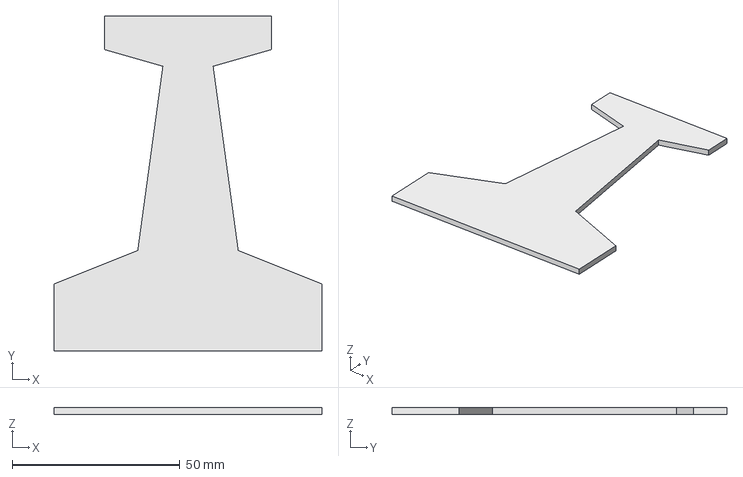
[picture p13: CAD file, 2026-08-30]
mechanics/Chassi.fcstd
80.0 x 100.0 x 2.00 mm

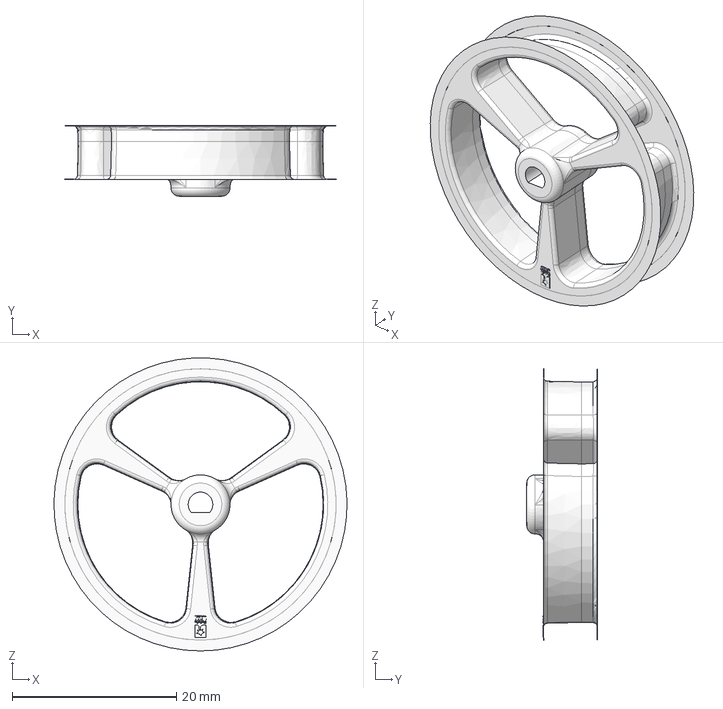
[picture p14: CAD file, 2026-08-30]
electronics/kicad-lib/3d/Pololu_wheel_40x7_hub.step
35.7 x 8.60 x 35.7 mm

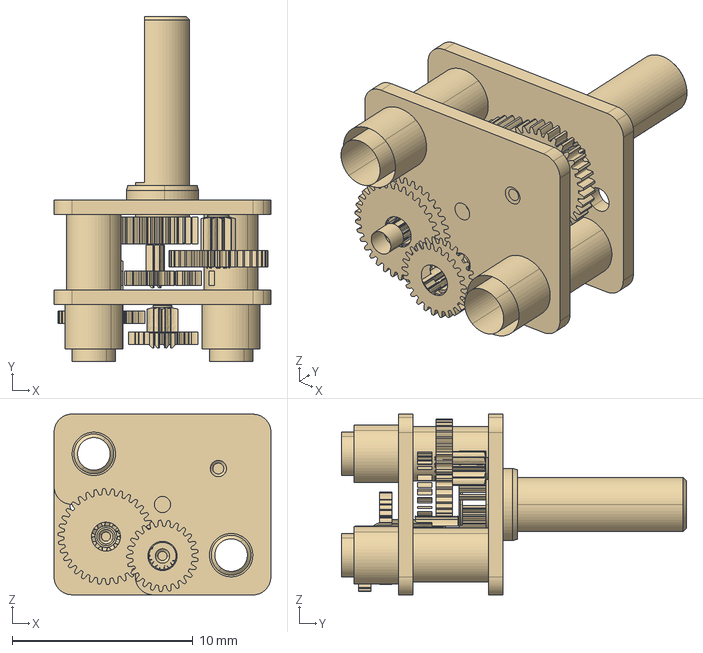
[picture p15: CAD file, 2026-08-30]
electronics/kicad-lib/3d/GM12-N20_motor_gearbox.step
12.0 x 19.1 x 10.0 mm

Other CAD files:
electronics/kicad-lib/3d/GM12-N20_bracket.step
electronics/kicad-lib/3d/GM12-N20_bracket.stl
mechanics/battery-holder-4xaa-1.snapshot.1/1_5V_holder4AA.x_t
mechanics/battery-holder-4xaa-1.snapshot.1/Batteria ricaricabile stilo.x_t

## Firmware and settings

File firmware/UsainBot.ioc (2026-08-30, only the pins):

Mcu.UserName=STM32G431KBTx
PA0.GPIO_Label=A0_QTR2
PA0.Signal=ADC2_IN1
PA1.GPIO_Label=A1_QTR1
PA1.Signal=ADC1_IN2
PA10.GPIO_Label=D0_DIST1
PA10.Signal=GPIO_Input
PA11.GPIO_Label=D10_DIST2
PA11.Signal=GPIO_Input
PA12.GPIO_Label=D2_ENC1_B
PA12.Signal=S_TIM4_CH2
PA13.GPIO_Label=T_SWDIO
PA13.Signal=SYS_JTMS-SWDIO
PA14.GPIO_Label=T_SWCLK
PA14.Signal=SYS_JTCK-SWCLK
PA15.GPIO_Label=D5_I2C_SCL
PA15.Signal=I2C1_SCL
PA2.GPIO_Label=A7_USART2_TX [ST-LINKV3E_VCP_RX]
PA2.Signal=USART2_TX
PA3.GPIO_Label=A2_USART2_RX [ST-LINKV3E_VCP_TX]
PA3.Signal=USART2_RX
PA4.GPIO_Label=A3_QTR7
PA4.Signal=ADC2_IN17
PA5.GPIO_Label=A4_QTR6
PA5.Signal=ADC2_IN13
PA6.GPIO_Label=A5_QTR3
PA6.Signal=ADC2_IN3
PA7.GPIO_Label=A6_QTR4
PA7.Signal=ADC2_IN4
PA8.GPIO_Label=D9_ENC2_B
PA8.Signal=S_TIM1_CH1
PA9.GPIO_Label=D1_ENC2_A
PA9.Signal=S_TIM1_CH2
PB0.GPIO_Label=D3_MOT1_PWM
PB0.Signal=S_TIM3_CH3
PB3.GPIO_Label=D13_MOT2_DIR
PB3.Signal=GPIO_Output
PB4.GPIO_Label=D12_MOT1_DIR
PB4.Signal=GPIO_Output
PB5.GPIO_Label=D11_MOT2_PWM
PB5.Signal=S_TIM3_CH2
PB6.GPIO_Label=D6_ENC1_A
PB6.Signal=S_TIM4_CH1
PB7.GPIO_Label=D4_I2C_SDA
PB7.Signal=I2C1_SDA
PB8-BOOT0.GPIO_Label=LD2 [green]
PB8-BOOT0.Signal=GPIO_Output
PF0-OSC_IN.GPIO_Label=D7_QTR8
PF0-OSC_IN.Signal=ADC1_IN10
PF1-OSC_OUT.GPIO_Label=D8_QTR5
PF1-OSC_OUT.Signal=ADC2_IN10

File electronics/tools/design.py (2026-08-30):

# -*- coding: utf-8 -*-
"""Genere le schema hierarchique KiCad du robot UsainBot."""
import os, sys
import kigen
from kigen import SymLib, Sheet, q, fmt, uid, ROOT_UUID, ROOT_FILE

HERE = os.path.dirname(os.path.abspath(__file__))
ELEC = os.path.abspath(os.path.join(HERE, '..'))          # .../electronics
DEST = sys.argv[1] if len(sys.argv) > 1 else ELEC
PRJ  = os.path.join(ELEC, 'kicad-lib')
LIB  = SymLib([PRJ])

DATE, REV, COMPANY = '2026-08-30', 'A', 'Pacabot'

# ------------------------------------------------------------------ empreintes
R06  = 'Resistor_SMD:R_0603_1608Metric'
R08  = 'Resistor_SMD:R_0805_2012Metric'
R12  = 'Resistor_SMD:R_1206_3216Metric'
C06  = 'Capacitor_SMD:C_0603_1608Metric'
C08  = 'Capacitor_SMD:C_0805_2012Metric'
C12  = 'Capacitor_SMD:C_1206_3216Metric'
C1210= 'Capacitor_SMD:C_1210_3225Metric'
CPOL = 'Capacitor_SMD:CP_Elec_6.3x7.7'
LED06= 'LED_SMD:LED_0603_1608Metric'
TP   = 'TestPoint:TestPoint_Pad_D1.5mm'
SOT23= 'Package_TO_SOT_SMD:SOT-23'

PWRLIB = {'GND': 'power', '+3V3': 'power', '+5V': 'power', 'VBUS': 'power',
          'PWR_FLAG': 'power',
          'VBAT': 'Pacabot', 'VPACK': 'Pacabot', '+3V3A': 'Pacabot', '+3V3_BLE': 'Pacabot'}
GNDISH = {'GND'}

# ------------------------------------------------------------------ raccords
def cx(sh, pin, spec, stub=2.54):
    """'@RAIL' -> symbole d'alim ; '$NET' -> label global ; 'NET' -> label local ; 'NC'."""
    if spec is None:
        return
    if spec == 'NC':
        sh.nc(pin); return
    if spec.startswith('@'):
        rail = spec[1:]
        end = pin.out(stub)
        if stub:
            sh.wire((pin.x, pin.y), end)
        # pas de coude : deux troncons paralleles ne se croisent jamais.
        # La broche du symbole d alimentation est a son origine, donc le tourner
        # ne deplace rien : on l oriente seulement pour que le dessin tombe juste.
        d = (round(pin.dx), round(pin.dy))
        if rail in GNDISH:
            rot = {(0, 1): 0, (0, -1): 180, (-1, 0): 90, (1, 0): 270}[d]
        else:
            rot = {(0, -1): 0, (0, 1): 180, (-1, 0): 270, (1, 0): 90}[d]
        sh.power_at(rail, end, PWRLIB[rail], rot=rot)
    elif spec.startswith('$'):
        sh.gnet(pin, spec[1:], stub)
    else:
        sh.net(pin, spec, stub)

def cx_bar(sh, part, nums, spec, offset=7.62, stub=2.54):
    """Plusieurs broches sur un meme net : une seule etiquette, pas une par broche.

    Les broches confondues (le BQ25887 double PMID, SW, SNS, BAT) sont
    dedoublonnees ; les broches espacees sont ramenees sur une barre commune.
    """
    pins, seen = [], set()
    for n in nums:
        p = part.pin(n)
        if (p.x, p.y) not in seen:
            seen.add((p.x, p.y))
            pins.append(p)
    if len(pins) == 1:
        cx(sh, pins[0], spec, stub)
        return
    net = spec[1:] if spec[0] in '@$' else spec
    end = sh.bar(pins, net, offset)
    d = (round(pins[0].dx), round(pins[0].dy))
    cx(sh, kigen.Pin(end[0], end[1], d[0], d[1], '', '', 'passive'), spec, stub)


def flag_net(sh, net, x, y, glob=True):
    """PWR_FLAG raccorde a un net nomme (le net n a pas de symbole d alim)."""
    sh.power_at('PWR_FLAG', (x, y), 'power')
    sh.wire((x, y), (x, y + 5.08), net)
    (sh.glabel_at if glob else sh.label_at)(net, (x, y + 5.08), (0, 1))

def flag(sh, rail, x, y):
    """Rail + PWR_FLAG cote a cote, pour satisfaire l'ERC."""
    sh.power_at(rail, (x, y), PWRLIB[rail], rot=180)
    sh.wire((x, y), (x + 5.08, y), rail)
    sh.power_at('PWR_FLAG', (x + 5.08, y), 'power', rot=180)

# --------------------------------------------------------------- deux-pattes
def vert(sh, lib_id, ref, val, x, y, top, bot, fp, fields=None, dnp=False):
    """Composant vertical : broche 1 en haut, broche 2 en bas."""
    p = sh.place(lib_id, ref, val, x, y, fp=fp, fields=fields, dnp=dnp,
                 ref_at=(x + 3.81, y - 1.27), val_at=(x + 3.81, y + 1.27))
    cx(sh, p.pin('1'), top)
    cx(sh, p.pin('2'), bot)
    return p

def horiz(sh, lib_id, ref, val, x, y, left, right, fp, fields=None, dnp=False):
    p = sh.place(lib_id, ref, val, x, y, fp=fp, fields=fields, dnp=dnp,
                 ref_at=(x, y - 5.08), val_at=(x, y - 2.54))
    a, b = p.pin('1'), p.pin('2')
    if a.x > b.x:
        a, b = b, a
    cx(sh, a, left)
    cx(sh, b, right)
    return p

def C(sh, ref, val, x, y, top, bot, fp=C06, fields=None):
    return vert(sh, 'Device:C', ref, val, x, y, top, bot, fp, fields)

def R(sh, ref, val, x, y, top, bot, fp=R06, fields=None, dnp=False):
    return vert(sh, 'Device:R', ref, val, x, y, top, bot, fp, fields, dnp)

def Rh(sh, ref, val, x, y, left, right, fp=R06, fields=None):
    return horiz(sh, 'Device:R', ref, val, x, y, left, right, fp, fields)

def tp(sh, ref, net, x, y, glob=True):
    p = sh.place('Connector:TestPoint', ref, net, x, y, fp=TP,
                 ref_at=(x + 2.54, y - 3.81), val_at=(x + 2.54, y - 1.27))
    cx(sh, p.pin('1'), ('$' + net) if glob else net)
    return p

def nmos_switch(sh, ref, x, y, gate_net, drain, rref, rg='100R', rgd='100k'):
    """AO3400A en commutation basse : serie de grille et rappel a la masse."""
    q_ = sh.place('Transistor_FET:AO3400A', ref, 'AO3400A', x, y, fp=SOT23,
                  ref_at=(x + 7.62, y - 2.54), val_at=(x + 7.62, y))
    gnode = f'{ref}_G'
    cx(sh, q_.pin('G'), gnode)
    cx(sh, q_.pin('S'), '@GND')
    cx(sh, q_.pin('D'), drain)
    r1, r2 = rref
    Rh(sh, r1, rg, x - 30, y, gate_net, gnode)
    R(sh, r2, rgd, x - 16, y + 18, gnode, '@GND')
    return q_
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

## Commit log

2026-08-30 Import initial du projet UsainBot
    Regroupe sous une racine unique le projet KiCad, la configuration CubeMX,
    la bibliothèque d'empreintes et de modèles 3D, les sources FreeCAD, le
    règlement de l'épreuve et le document d'architecture.
    Corrige au passage les chemins de bibliothèque : les références passent de
    ${KIPRJMOD}/../../kicad-lib à ${KIPRJMOD}/../kicad-lib après la
    réorganisation, et les cinq modèles 3D qui pointaient vers un chemin absolu
    sous /Users/zhonx sont ramenés en relatif. Le dépôt s'ouvre désormais tel
    quel après clonage.
    [1_5V_holder4AA.x_t, Batteria ricaricabile stilo.SLDPRT, Batteria ricaricabile stilo.x_t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]
2026-08-30 Réorganise le dépôt par discipline et adopte le nom UsainBot
    Le dépôt s'appelle UsainBot : les dernières mentions de « Pacabot Junior »
    disparaissent du README de la bibliothèque, de la description de fp-lib-table
    et de l'en-tête du document d'architecture.
    Sépare les métiers à la racine, dans le vocabulaire déjà en usage sur les
    autres dépôts de l'organisation : electronics, firmware, mechanics,
    documentation, rules. La bibliothèque KiCad rejoint electronics/, ce qui
    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
    [1_5V_holder4AA.x_t, Batteria ricaricabile stilo.SLDPRT, Batteria ricaricabile stilo.x_t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]
2026-08-30 Corrige l'analyse du télémètre analogique : détection synchrone
    L'objection en 1/d² était juste mais incomplète, et la conclusion qui en
    découlait était fausse. Un mètre de portée avec un OPV302 et un BPW77 est
    crédible dès lors que le continu ambiant est supprimé en amont du gain et
    que l'émission est modulée puis démodulée en synchrone. Le traitement ne
    réduit pas la perte optique, il rend le signal restant exploitable.
    Distingue explicitement les deux régimes de mesure, que le terme
    « soustraction d'ambiante » confondait : soustraction numérique en trois
    phases pour la barrette de ligne, où le signal abonde à 3 mm ; couplage
    alternatif et détection synchrone pou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
2026-08-30 Adopte la télémétrie analogique partout et dégraisse le document
    Les trois visées — avant, diagonale à 45°, latéral gauche — passent sur des
    stations OPV302 + BPW77 à détection synchrone. Le VL53L1X et le bus I²C des
    télémètres disparaissent du schéma bloc, de l'implantation, des élévations,
    du tableau des broches et de la nomenclature.
    Corrige la géométrie des élévations, qui reposait sur le cône de 27° d'un
    capteur à temps de vol. Un émetteur collimaté visé parallèlement au sol ne
    l'éclaire jamais, et la démodulation synchrone ignore ce qui n'est pas
    modulé : la hauteur de 45 mm ne couvre plus une ouverture mais la tolérance
    de visée, ± 2° sur toute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
2026-08-30 Monte les diodes de télémétrie sur la carte et acte les cotes de l'OPV302
    Corrige l'hypothèse de collimation. La fiche technique TT Electronics
    Rev C 09/2018 donne un VCSEL 850 nm en TO-46 à lentille dôme, divergence
    4° FWHM, soit un demi-angle de 2°. Étroit, mais pas parallèle : la tache
    mesure 42 mm à 600 mm et 70 mm à 1 m.
    Adopte la pratique du micromouse : diodes soudées à plat sur la carte
    mère, boîtier couché sur pattes cintrées, inclinées de 4° vers le haut.
    Le rayon bas du faisceau monte alors de 35 mm par mètre et n'atteint
    jamais la bâche. La carte verticale sécable disparaît, et avec elle le
    dernier motif de découper le PCB : une seule carte, sans excepti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
2026-08-30 Tranche la question de la montée en fréquence et corrige l'analyse de sécurité
    Monter à des impulsions de 1 µs à 100 kHz débloque bien les 48 mA, mais
    n'apporte rien : les deux régimes autorisés par la fiche technique
    délivrent exactement 1,26 mW de puissance optique moyenne, ce qui n'est
    pas fortuit puisqu'ils dérivent de la même limite thermique. Un détecteur
    synchrone accumule une énergie et le bruit d'ambiance a une densité
    spectrale plate : le rapport signal sur bruit atteint en un temps donné
    est identique. Le coût, lui, est réel — trois amplificateurs
    transimpédance pour laisser passer des impulsions d'une microseconde.
    Identifie le levier qui fonctionne : la su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
2026-08-30 Dessine le schéma complet de la carte sur sept feuilles hiérarchiques
    Le projet KiCad ne portait qu'une feuille vide. Il contient maintenant les
    252 composants de la carte, répartis par fonction : alimentation et charge
    USB-C, microcontrôleur, ponts en H, barrette de ligne, capteurs, IHM,
    traces et turbine. Les feuilles communiquent par étiquettes globales
    plutôt que par entrées de feuille : un bloc se lit seul, et renommer un
    signal ne demande pas de retoucher la racine. ERC à zéro erreur et zéro
    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
    [01-power.kicad_sch, 02-mcu.kicad_sch, 03-motors.kicad_sch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]
2026-09-06 Ignore les sauvegardes de travail et les journaux des générateurs
    Deux familles de fichiers apparaissaient à chaque séance sans avoir rien
    à faire dans l'historique : les copies `design.py.bak` et `.bak2` laissées
    avant une refonte, et le compte rendu que `telemetry_duo.py` écrit à côté
    du modèle qu'il exporte. Tous se régénèrent ou ne servent qu'une heure.
2026-09-06 Retire les pièces mécaniques que le projet a laissées derrière lui
    `CarteMere.fcstd` et `Chassi.fcstd` étaient les deux esquisses du premier
    tour de conception, quand la carte n'était qu'un rectangle et le châssis
    une plaque à découper. Le contour vient maintenant du PCB lui-même
    — 194 × 155 mm, nez ajouré, perçage de turbine — et les pièces qui
    comptent sont générées par script dans `mechanics/`. Garder deux documents
    FreeCAD figés à côté ne pouvait que faire diverger les cotes.
    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
2026-09-06 Modélise les quatre pièces qui décident de l'encombrement de la carte
    Chacune est un module paramétrique FreeCAD, exporté en STEP coloré pour que
    KiCad montre en 3D ce que la carte devra loger. Le dossier ne contient plus
    de plan figé : la cote se change dans le script, tout le reste suit.
    `turbineEDF27.py` — l'EDF 27 mm AEORC POWER-X, ⌀36,7 hors-tout pour 25,8 de
    long. Modèle d'intégration, pas d'aérodynamique : les diamètres, la longueur
    et le nombre de pales sont à la cote, le profil est représentatif.
    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
2026-09-06 Dote la bibliothèque des pièces que la carte doit porter en vrai
    Dix empreintes et dix-neuf modèles 3D entrent dans `kicad-lib`, tous
    générés par script et tous documentés dans le README : sans eux le contrôle
    d'encombrement était aveugle là où vivent justement les pièces les plus
    hautes.
    La motorisation d'abord. `faulhaber_geom.py` porte les cotes en source
    unique — 1524T006SR, codeur IE2-1024, réducteur 15/10 à 3,33:1 — et trois
    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
2026-09-06 Passe le microcontrôleur en LQFP144 et lit les deux courants au même instant
    Le LQFP100 avait ses seize entrées ADC prises — douze voies de ligne, trois
    de télémétrie, une sortie de multiplexeur — et c'est ce multiplexeur qui
    posait le vrai problème : il interdisait par construction de lire les deux
    courants moteur ensemble. On lisait un moteur, on commutait, on attendait
    l'établissement, on lisait l'autre. Le STM32H723ZGT6 en LQFP144 place
    PF11 sur ADC1_INP2 et PF13 sur ADC2_INP2 : même numéro de voie sur deux
    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
2026-09-06 Pose les 335 composants sur la carte, chacun contre l'actif qu'il sert
    Le PCB ne portait que le contour. Il porte maintenant tout le schéma, placé
    par script : la position de chaque composant est écrite dans `layout.py`,
    jamais posée à la souris. Les rangées de résistances alignées loin de leur
    circuit ont disparu ; à leur place une grappe par fonction, au contact du
    boîtier. Ce qui ne pouvait pas suivre — les passifs lents des deux ponts en
    H, coincés derrière l'équerre moteur — est regroupé en un bloc unique plutôt
    que dispersé.
    Six zones sur 194 × 155 mm. L'arrière, seule bande libre devant les
    équerres, prend les ponts en H aux deux angles, le chargeur, l'USB et l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
2026-09-06 Déduit les cinq cotes de roulage au lieu de les choisir au catalogue
    Le chapitre d'implantation partait d'un rectangle de 120 × 180 et de trois
    principes. Il part maintenant du règlement — rayon minimum de 20 cm, ligne
    de 19 mm, marques du chapitre 3 — et de la motorisation retenue, 1524T006SR
    avec réducteur 3,33:1 sur roues JS4311 de 43 mm, pointe d'environ 5,2 m/s.
    Les cinq cotes forment un système, et c'est l'avance de la moustache qui
    commande tout le reste.
    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
2026-09-13 Dote la bibliothèque du connecteur, de l'ESC et du capteur que la carte porte vraiment
    Quatre empreintes et huit modèles 3D entrent dans `kicad-lib`, chacun pour
    remplacer une pièce qu'un contrôle 3D a prise en défaut.
    `ITR8307_S17_TR8_Bottom` d'abord, parce que l'erreur était héritée et
    invisible à plat. L'ancienne `ITR8307_dessous` copiait la variante à
    fenêtre, pattes à 6,7 mm, alors que la référence C81632 désigne le
    S17/TR8(B) à pattes formées, portée 4,6 mm, sans découpe. Retirer le
    contour Edge.Cuts ne corrigeait donc pas le boîtier. La nouvelle empreinte
    suit le dessin Everlight DRX-0000322 rév. 6 : corps 3,4 × 2,7, 1,62 mm de
    haut nominal, pieds à (±0,9 ; ±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
2026-09-13 Replace la carte autour de ses chaînes analogiques et y intègre le pack commun et l'ESC
    Le placement du 4 septembre rangeait les pièces par zone. Celui-ci part des
    nets et des vraies pastilles, et affecte chaque condensateur à une broche
    plutôt qu'à une couronne autour du boîtier. Le STM32 pivote de 180° sur son
    centre pour tourner son côté analogique vers la barrette. Chaque station
    laser reçoit son propre TLV9064 (U504 s'ajoute pour la station L), et la
    liaison photodiode → TIA tombe de 34, 56 et 69 mm à 3,1, 7,4 et 2,9 mm. La
    boucle de retour du TIA passe de 140–150 mm à 3,55. Cinq découplages
    suivent : C568, C569/C570 sur VREF_RX, C223/C224 sur VBAT du MCU et C351
    sur V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
2026-09-13 Verse au dépôt les trois revues qui justifient la carte actuelle
    Chaque étape du 6 et du 7 septembre laisse un dossier : un rapport qui dit
    ce qui a changé et ce qui reste ouvert, les scripts qui l'ont produit, et
    les résultats bruts sur lesquels il s'appuie (ERC, DRC, géométrie, rendus,
    schéma PDF).
    `placement-review/` trace le replacement autour des chaînes analogiques,
    avec la table des rôles et distances de chaque passif. `integration-review/`
    couvre les témoins de ligne, l'ESC Bullet 12A, le pack commun et la
    correction du boîtier S17. Son `esc-research.md` détaille comment les pads
    ont été relevés sur photo, et avec quelle incertitude. `mr30-review/`
    documente le rempl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
2026-10-02 Réenregistre la carte au format KiCad 10.99 et retouche dix placements
    État de travail de l'utilisateur, commité tel quel avant la pose des
    règles de conception : passage au format 20260901 du fork (transform,
    réglages BOM, réglages DRC nouveaux) et déplacement de C214, C569, C543,
    C568, C119, FB101, R546, R545, R547 et C522.
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
